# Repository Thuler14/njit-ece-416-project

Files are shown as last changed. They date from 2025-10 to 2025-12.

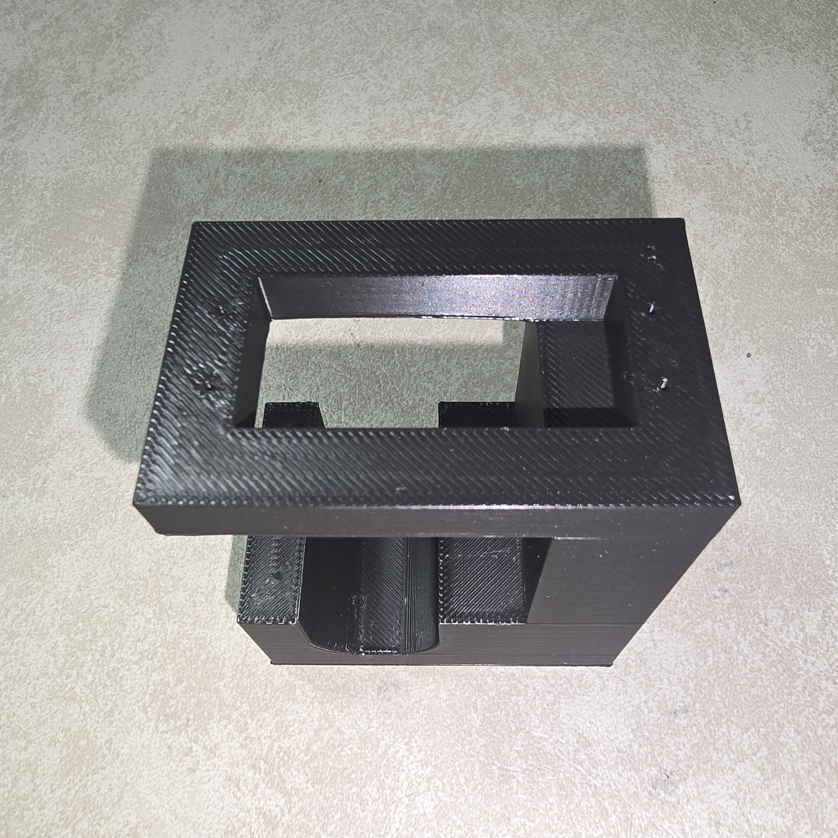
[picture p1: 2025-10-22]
mechanical/photos/m1_servo_mount_3.jpg

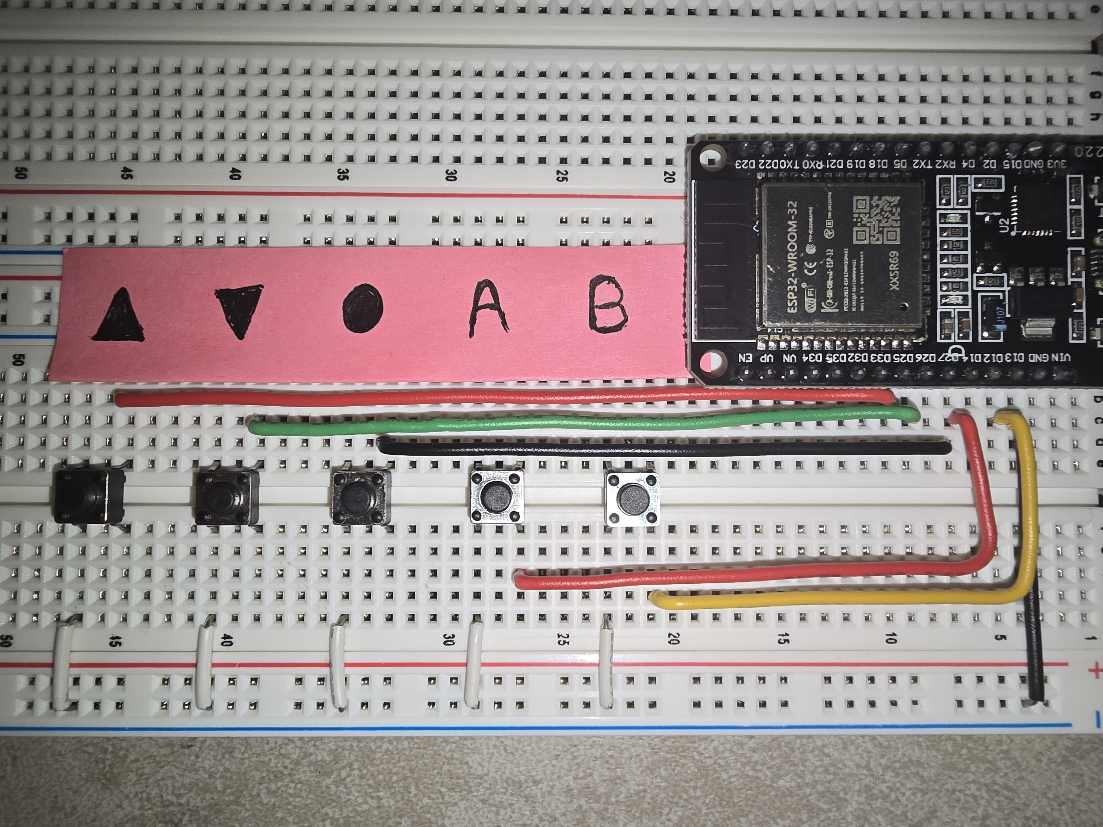
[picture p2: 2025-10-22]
mechanical/photos/m1_push_button_wiring.jpg

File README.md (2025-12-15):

# Automatic Temperature-Controlled Shower

ESP32-based prototype that mixes hot/cold water to a user-selected setpoint using temperature sensors, a servo-driven valve pair, and a simple UI. Built for NJIT ECE 416.

## Quick Start (Arduino IDE)
1. Install **esp32 by Espressif Systems** via Boards Manager.
2. Libraries: **OneWire**, **DallasTemperature**, **ESP32Servo**, **U8g2**.
3. Configure firmware:
   - `firmware/common/config.h`: set control/UI MACs (scan with `firmware/tools/m2_mac_scan/`), comm channel, and optional ESP-NOW encryption keys.
   - `firmware/control/config.h`: set DS18B20 addresses (scan with `firmware/tools/m1_temp_scan/`) and servo min/max values (from `firmware/tools/m1_servo_calibration/`).
4. Build/upload in two IDE windows:
   - `firmware/control/control.ino` → Control unit (sensors, PID, servos, flow, E-stop).
   - `firmware/ui/ui.ino` → UI unit (buttons, OLED, presets, ESP-NOW sender).
5. Power both boards; UI shows outlet temp and link status. Toggle run/stop from the UI. Serial output on the control unit emits CSV logs (10 Hz) when `PID_LOG_CSV` is enabled.

## Data Logging & Plots
- Control firmware prints CSV logs over USB. Capture to file with your serial monitor or use `tests/scripts/m2_logger_live_plot.py --port /dev/tty... --outfile tests/data/run.csv` to live-plot and save.
- Offline plotting: `python3 tests/scripts/m2_logger_plot.py --pattern my_run*.csv` saves PNGs to `tests/reports/`.
- Python deps: `pandas`, `matplotlib`, and `pyserial` (for live logging).

## Repository Structure
```text
njit-ece-416-project/
├─ firmware/
│  ├─ common/           # Shared comm + setpoint config
│  ├─ control/          # ESP32 control unit (sensors, PID, servos)
│  ├─ ui/               # ESP32 UI unit (buttons, OLED, ESP-NOW)
│  ├─ examples/         # Milestone demos
│  ├─ libraries/        # Local Arduino libs (if any)
│  └─ tools/            # Address/servo calibration sketches
├─ mechanical/
│  ├─ cad/              # 3D models, mounts, enclosure
│  └─ photos/           # Assembly & testbed images
├─ tests/
│  ├─ data/             # CSV logs (temp, flow, servo_us, setpoint)
│  ├─ scripts/          # Analysis helpers (optional)
│  └─ reports/          # Validation results & plots
└─ design/              # Wiring diagrams, block diagram, pin maps, calibration notes
```

## Safety
- Max outlet temp **120 °F** (hard limit in firmware).  
- Link-loss or sensor fault → system defaults to **cold-safe**.  
- Hardware E-stop cuts servo power and forces valve closed. 

## Contributing
- Open an Issue first for features/bugfixes; note required hardware (control/UI boards, sensors, flow).
- Work from a fork or branch off `main`. Touch the relevant area (`firmware/`, `tests/`, `mechanical/`, `design/`) and keep evidence in `tests/data` and `tests/reports`.
- Firmware: use the Arduino libs listed above; only change `firmware/common/config.h` and `firmware/control/config.h` when necessary, and document MAC/address updates.
- Scripts/plots: keep deps to `pandas`, `matplotlib`, `pyserial`; include example commands in your PR.
- Open a PR with a concise summary and evidence paths; call out any safety-impacting changes.

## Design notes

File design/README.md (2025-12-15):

# design
System design artifacts: block/wiring diagrams, pin maps, and configuration notes for the ESP32 control + UI units.

## Contents
- `wiring/` — wiring diagrams and pin tables for sensors, servos, flow sensor, E-stop, OLED, and buttons.
- `config/` — design-time notes for ESP-NOW, PID constants, setpoint presets, and component specifics (OLED, temp sensors, flow sensor, buttons, servos).

## Conventions
- Keep editable sources (Draw.io/Fritzing/etc.) next to exported PNG/PDF.
- Note any calibration values or pin swaps that need to be mirrored in `firmware/common/config.h` and `firmware/control/config.h`.

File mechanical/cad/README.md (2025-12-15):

# mechanical/cad
Fusion 360 models for mounts, enclosure pieces, and printable hardware.

## Layout
- `servo_mount/` — bracket to hold the MG996R servo at the valve.
- `valve_coupler/` — coupler between servo horn and valve stem.
- `exports/` — STL exports for printing (name by milestone/task).

Add new variants with a short note on fitment/tolerances; keep param edits in the CAD source and export fresh STLs when dimensions change.

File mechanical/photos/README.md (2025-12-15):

# mechanical/photos
Assembly and testbed photos (wiring, leak tests, waterproofing, mounts).

- Name files by milestone/task (ex: `m2_servo_mount.jpg`, `m3_estop_wiring.jpg`).
- Add a brief caption in a `.md` or `_notes.txt` if the photo shows something non-obvious (orientation, clearances, torque notes).

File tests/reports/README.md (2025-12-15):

# tests/reports
Validation outputs: plots, screenshots, and media from milestone runs (temperature control, safety, leak, flow).

- `tests/scripts/m2_logger_plot.py` writes PNGs here using the CSV stem.
- Name artifacts by milestone/task (ex: `m2_closedloop.png`, `m3_fault_demo.mp4`) and mention the source CSV or hardware setup in the report/PR.

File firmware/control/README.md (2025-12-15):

# firmware/control
ESP32 firmware for the control unit: temperature sensors, PI loop, dual servos, flow sensing, and safety interlocks.

## Setup
- Open `control.ino` in Arduino IDE (ESP32 board support installed).
- Libraries: **OneWire**, **DallasTemperature**, **ESP32Servo**.
- Configure hardware constants in `config.h`:
  - Set DS18B20 ROM addresses (scan with `firmware/tools/m1_temp_scan/`).
  - Servo min/max µs from `firmware/tools/m1_servo_calibration/`.
- Match ESP-NOW MAC/channel/encryption with `firmware/common/config.h`.

## Operation
- Receives setpoint + run/stop from the UI unit via ESP-NOW.
- Polls hot/cold/outlet DS18B20s at 10 Hz with plausibility + rapid-change checks.
- Drives two MG996R servos to mix hot/cold; monitors flow (YF-S201) and E-stop.
- CSV logging (10 Hz) is enabled when `PID_LOG_CSV` is true; capture via USB serial to `tests/data/`. Header: `ms,setF,T_out_raw,T_out_filt,ratio,u,Kp,Ki,flow_lpm,link_ok`.

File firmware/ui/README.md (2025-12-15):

# firmware/ui
ESP32 firmware for the user interface unit: buttons, OLED, presets, and ESP-NOW link to the control unit.

## Setup
- Open `ui.ino` in Arduino IDE (ESP32 board support installed).
- Library: **U8g2** for the SSD1309 OLED.
- Ensure `firmware/common/config.h` MAC/channel/encryption match the control unit.
- Button/OLED pinout lives in `config.h` (defaults: ▲▼● A/B on GPIO 25/26/27/14/13).

## Operation
- Sends setpoint + run/stop to the control unit; sends heartbeat every second.
- UI shortcuts: ▲/▼ adjust setpoint, presets A/B defined in `firmware/common/config.h`.
- Screen shows outlet temp, link status, and flow (when provided by the control unit).
- Control link is over ESP-NOW; update preset values or default setpoint in `firmware/common/config.h`.

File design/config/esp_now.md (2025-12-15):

# ESP-NOW Communication — Configuration

## Overview

- The system uses **ESP-NOW** for direct, low-latency wireless communication between the **Control** and **UI** modules.
- Both ESP32 boards operate in **Station (STA)** mode on a fixed Wi-Fi channel to maintain a stable one-to-one link.
- MAC addresses and encryption keys are configured in [`firmware/config/config.h`](../../firmware/common/config.h).

---

## MAC Addresses

| Constant | Device | Value |
|:--|:--|:--:|
| `COMM_CTRL_MAC` | Control unit | `3C:8A:1F:80:A9:D4` |
| `COMM_UI_MAC` | UI unit | `8C:4F:00:35:9B:F4` |

> Discovered using [`firmware/tools/m2_mac_scan/m2_mac_scan.ino`](../../firmware/tools/m2_mac_scan/m2_mac_scan.ino).

---

## Communication Constants

| Constant | Description | Value |
|:--|:--|:--:|
| `COMM_CHANNEL` | Wi-Fi channel used for both boards | `6` |
| `COMM_USE_ENCRYPTION` | Enable/disable ESP-NOW encryption (`true`/`false`) | `false` |

---

## Encryption Keys

| Constant | Description | Value |
|:--|:--|:--:|
| `COMM_PMK` | Primary Master Key (global) | `showerctrl_pmk16` |
| `COMM_LMK` | Local Master Key (per-peer key) | `static_lmk_uictr` |

---

## Protocol

| Constant | Description | Value |
|:--|:--|:--:|
| `COMM_PROTOCOL_VERSION` | Protocol version | `1` |
| `COMM_FLAG_ACK` | Acknowledgment bit | `1 << 0` |
| `COMM_FLAG_RUN` | Run/Stop bit | `1 << 1` |
| `COMM_FLAG_ERR` | Error bit | `1 << 2` |

---

## Data Structure

`COMM_Payload` defines the transmitted packet containing timestamp, sequence number, setpoint, and flag bits used for control and acknowledgment.

---

## Notes
- Each board uses the **other board’s MAC address** as its peer.
  - UI → `CTRL_MAC`  
  - Control → `UI_MAC`
- Both must share the same **channel** and, if encryption is enabled, the **same PMK/LMK pair**.

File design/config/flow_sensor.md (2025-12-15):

# Flow Sensor (YF-S201) - Configuration

## Overview

- The control module uses one **YF-S201** Hall-effect flow sensor to measure the total outlet flow rate.
- The sensor outputs a digital pulse signal proportional to flow velocity, detected via an interrupt on the ESP32. 
- Configuration constants are defined in [`firmware/control/config.h`](../../firmware/control/config.h).

---

## Hardware Constants

| Constant | Description | Value |
|:--|:--|:--:|
| `FLOW_PIN` | GPIO used for pulse input | `21` |

---

## Measurement Constants

| Constant | Description | Value |
|:--|:--|:--:|
| `FLOW_K_PULSES_PER_ML` | K-factor — pulses per mL of water (≈7500/L) | `7.5f` |
| `FLOW_WINDOW_MS` | Sampling window for pulse counting (ms) | `500` |
| `FLOW_FILTER_TAU_MS` | EMA time constant for smoothing flow readings (ms) | `1000` |

---

## Notes

- The **K-factor (7.5 pulses/mL)** depends on the specific sensor and flow path and will be refined during **M3 calibration**.  
- The current sampling window of **500 ms** balances noise reduction with responsiveness.

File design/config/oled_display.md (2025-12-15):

# OLED Display — Configuration

## Overview

- The system uses a **128×64 px SSD1309** OLED driven over **SPI** using the **U8g2** graphics library.
- It shows setpoint, run state, and status indicators for transmission activity.
- Display configuration is defined in [`firmware/ui/config.h`](../../firmware/ui/config.h).

---

## Hardware Constants

| Constant | Description | Value |
|:--|:--|:--:|
| `OLED_PIN_CS` | Chip Select (CS) | `5` |
| `OLED_PIN_DC` | Data/Command (DC) | `22` |
| `OLED_PIN_RST` | Reset (RST) | `4` |

---

## U8g2 Setup (firmware)

- Rotation: `U8G2_R0` (no rotation)
- Constructor: `U8G2_SSD1309_128X64_NONAME2_F_4W_HW_SPI`

---

## Notes

- Operates on 3.3 V logic.  
- Use full-buffer (`_F_`) U8g2 variants for stable screen refresh.

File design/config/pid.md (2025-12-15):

# PID Controller — Configuration

## Overview

- PI(D) controller drives the hot/cold valve mix ratio to hold the outlet temperature at the setpoint.  
- PID configuration is defined in [`firmware/control/config.h`](../../firmware/control/config.h).

---

## Control Gains and Limits

| Parameter | Description | Value |
|:--|:--|:--:|
| `PID_KP` | Proportional gain | `0.10` |
| `PID_KI` | Integral gain (per second) | `0.08` |
| `PID_KD` | Derivative gain | `0.00` |
| `PID_OUT_MIN` | Output lower bound (mix ratio) | `0.0` |
| `PID_OUT_MAX` | Output upper bound (mix ratio) | `1.0` |

---

## Notes

- Integrator is clamped to `[PID_OUT_MIN, PID_OUT_MAX]` to limit windup.  
- Timing uses measured loop intervals (`millis()` delta) with a 12 ms target delay; retune if the loop rate changes.

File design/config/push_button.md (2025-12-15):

# Push Buttons — Configuration

## Overview

- Five **momentary pushbuttons** provide local user input for temperature control and preset functions.
- Each button is connected to an **ESP32 GPIO** with **internal pull-ups enabled** (active-low).
- Button configuration is defined in [`firmware/ui/config.h`](../../firmware/ui/config.h).

---

## Hardware Constants

| Constant | Description | Value |
|:--|:--|:--:|
| `BTN_PIN_UP` | Increase setpoint (▲) | `25` |
| `BTN_PIN_DOWN` | Decrease setpoint (▼) | `26` |
| `BTN_PIN_OK` | Run/Stop toggle (●) | `27` |
| `BTN_PIN_A` | Preset A | `14` |
| `BTN_PIN_B` | Preset B | `13` |

---

## Timing Constant

| Constant | Description | Value (ms) |
|:--|:--|:--:|
| `BTN_DEBOUNCE_MS` | Time a level must be stable before recognized | `20` |
| `BTN_DBLCLICK_MS` | Maximum time between two clicks | `350` |
| `BTN_LONGPRESS_MS` | Hold duration to count as long-press | `800` |
| `BTN_REPEAT_DELAY_MS` | Wait before first repeat event | `500` |
| `BTN_REPEAT_MS` | Interval between repeats | `150` |

---

## Notes

- Buttons are **active-low**, meaning a press reads `LOW`.
- Presets A and B correspond to user-defined temperature shortcuts.

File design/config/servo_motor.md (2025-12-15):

# Servo Motors (MG-996R) — Configuration

## Overview

- Two **MG996R servo motors** are used to control the cold and hot water valves.  
- Each servo is calibrated for fully closed and fully open positions, with pulse widths defined in [`firmware/control/config.h`](../../firmware/control/config.h).
- The calibration ensures consistent mechanical limits and prevents overtravel.

---

## Hardware Constants

| Constant | Description | Value |
|:--|:--|:--:|
| `SERVO_PIN_HOT` | GPIO pin for hot valve servo | `19` |
| `SERVO_PIN_COLD` | GPIO pin for cold valve servo | `18` |

## Calibration Constants

| Constant | Description | Typical Value (µs) |
|:--|:--|:--:|
| `SERVO_HOT_MIN_US` | Hot valve — fully **open** position | `1180` |
| `SERVO_HOT_MAX_US` | Hot valve — fully **closed** position | `2080` |
| `SERVO_COLD_MIN_US` | Cold valve — fully **open** position | `1120` |
| `SERVO_COLD_MAX_US` | Cold valve — fully **closed** position | `2080` |
| `SERVO_GUARD_US` | Safety margin from mechanical stop | `15` |

> Calibrated using [`firmware/tools/servo_calibration/m1_servo_calibration.ino`](../../firmware/tools/m1_servo_calibration/m1_servo_calibration.ino).

---

## Notes

- Guard offsets prevent mechanical stress by reducing servo travel slightly before reaching the physical stop.
- The calibrated limits correspond to real valve endpoints; any adjustments should be re-measured and updated in `config.h`.

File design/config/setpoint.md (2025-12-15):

# Temperature Setpoint — Configuration

## Overview

- Defines default, safety, and preset temperature values for system operation.  
- Values are expressed in **degrees Fahrenheit (°F)**.  
- Configuration is defined in [`firmware/ui/config.h`](../../firmware/common/config.h).

---

## Setpoint Constants

| Constant | Description | Value (°F) |
|:--|:--|:--:|
| `SETPOINT_DEFAULT_F` | Default setpoint at startup | `100.0` |
| `SETPOINT_MIN_F` | Minimum safety limit | `80.0` |
| `SETPOINT_MAX_F` | Maximum safety limit | `120.0` |
| `SETPOINT_STEP_F` | Adjustment step size | `1.0` |
| `SETPOINT_PRESET_A_F` | Preset A value | `98.0` |
| `SETPOINT_PRESET_B_F` | Preset B value | `105.0` |

---

## Notes

- All limits are enforced in firmware to prevent unsafe temperature selection.  
- Preset A and B provide quick access to preferred comfort temperatures.

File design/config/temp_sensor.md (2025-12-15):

# Temperature Sensors (DS18B20) - Configuration

## Overview

- The control module uses three DS18B20 digital temperature sensors connected via a shared OneWire bus.  
- Each sensor has a unique 64-bit ROM address and is configured in [`firmware/control/config.h`](../../firmware/control/config.h).

---

## Hardware Constants 

| Constant | Description | Value |
|:--|:--|:--:|
| `TEMP_PIN_ONEWIRE` | GPIO pin for DS18B20 data line | `4` |
| `TEMP_HOT_ADDR` | Hot inlet sensor | `0x289DE1BA00000078` |
| `TEMP_COLD_ADDR` | Cold inlet sensor | `0x2884B3B4000000B6` |
| `TEMP_OUT_ADDR` | Outlet sensor | `0x284DF1BA000000C0` |

> Discovered using [`firmware/tools/m1_temp_scan/m1_temp_scan.ino`](../../firmware/tools/m1_temp_scan/m1_temp_scan.ino).

---

## Timing Constants

| Constant | Description | Value |
|:--|:--|:--:|
| `TEMP_RESOLUTION` | DS18B20 resolution (9–12 bits) | `9` |
| `TEMP_CONVERSION_TIME_MS` | Max conversion time for chosen resolution | `94` |
| `TEMP_LOOP_DT_MS` | Loop interval for temperature read (ms) | `100` |

---

## Filtering Constants

| Constant | Description | Value |
|:--|:--|:--:|
| `TEMP_EMA_ALPHA` | EMA smoothing factor (τ ≈ 0.4 s @ 10 Hz) | `0.20f` |
| `TEMP_MIN_VALID_C` | Minimum valid temperature (°C) | `-60.0f` |
| `TEMP_MAX_VALID_C` | Maximum valid temperature (°C) | `125.0f` |

---

## Notes

- ROM addresses are unique identifiers used to bind each DS18B20 to its physical position.  
- Configuration constants apply globally to all temperature sensors unless overridden.  
- 9-bit mode allows a full conversion within the 100 ms loop.

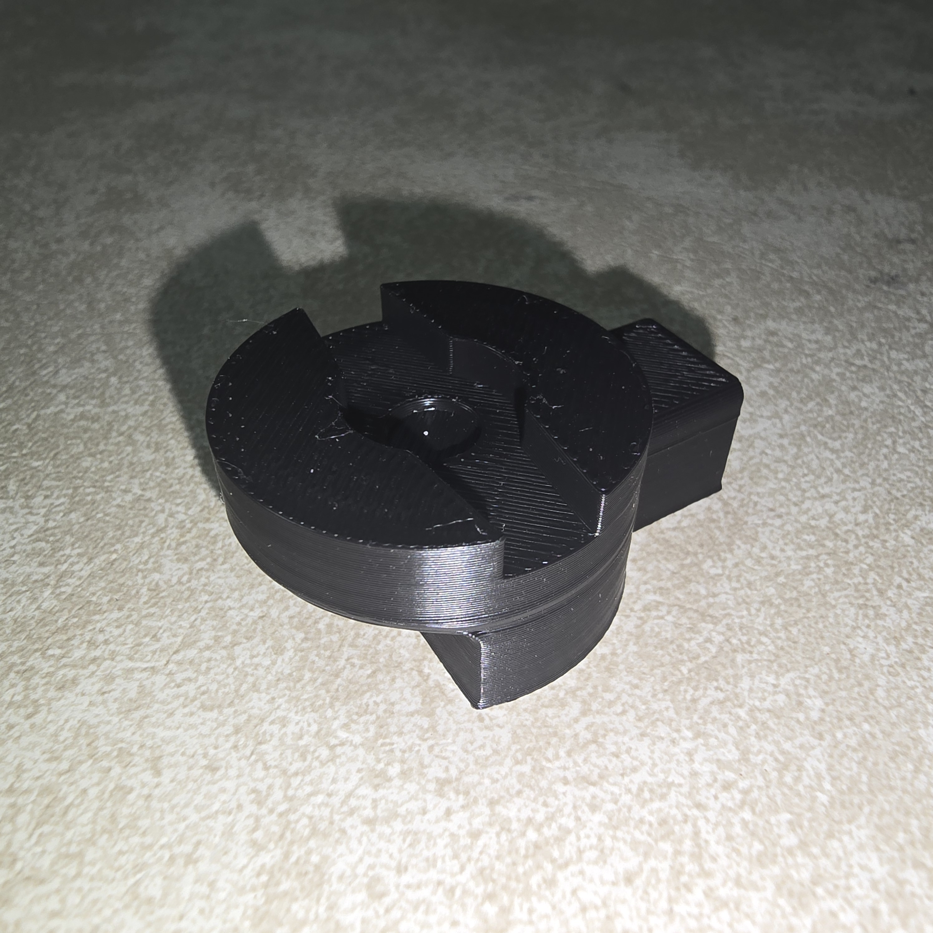
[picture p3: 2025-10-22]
mechanical/photos/m1_valve_coupler_1.jpg

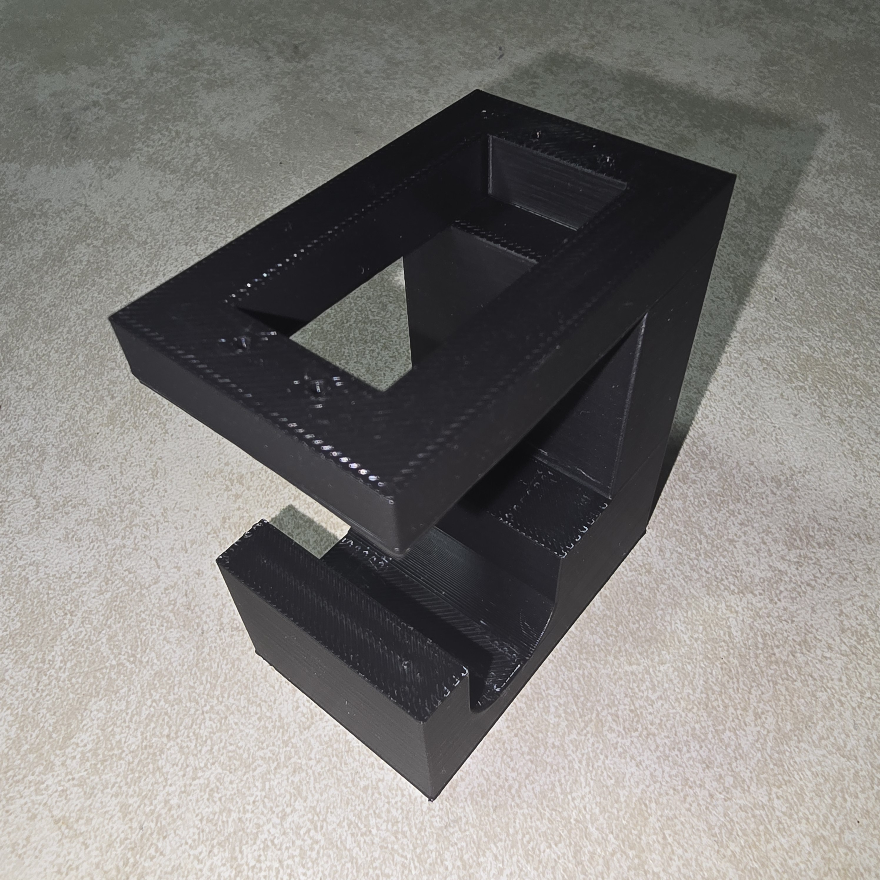
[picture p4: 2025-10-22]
mechanical/photos/m1_servo_mount_1.jpg

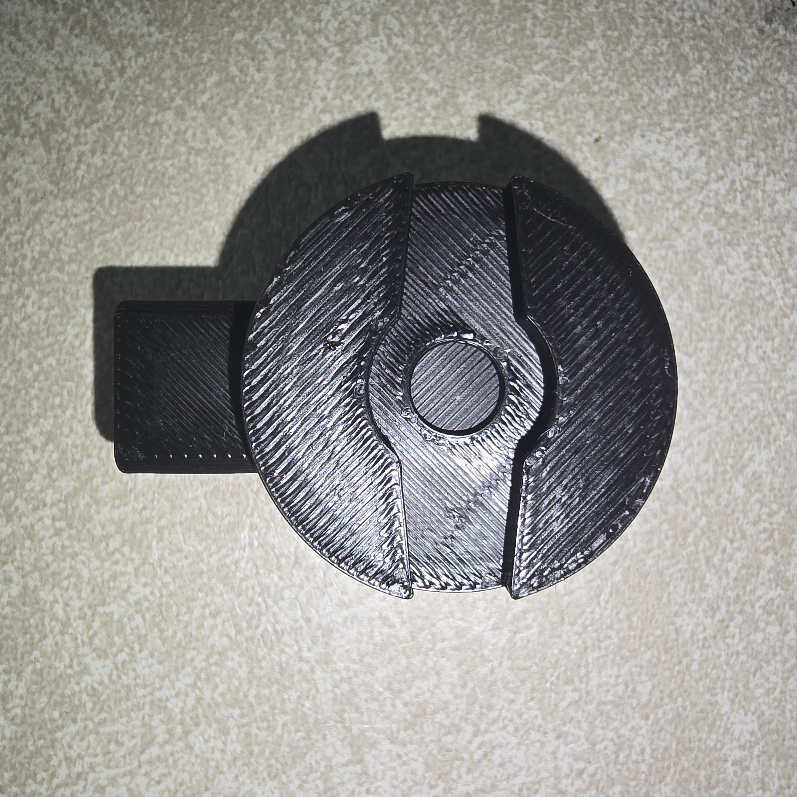
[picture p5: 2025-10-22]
mechanical/photos/m1_valve_coupler_2.jpg

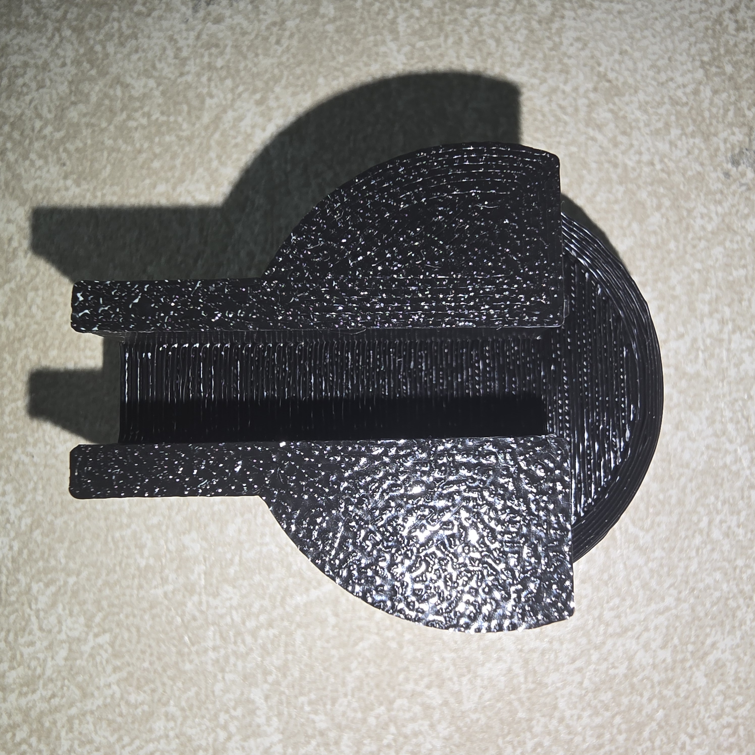
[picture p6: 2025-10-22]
mechanical/photos/m1_valve_coupler_3.jpg

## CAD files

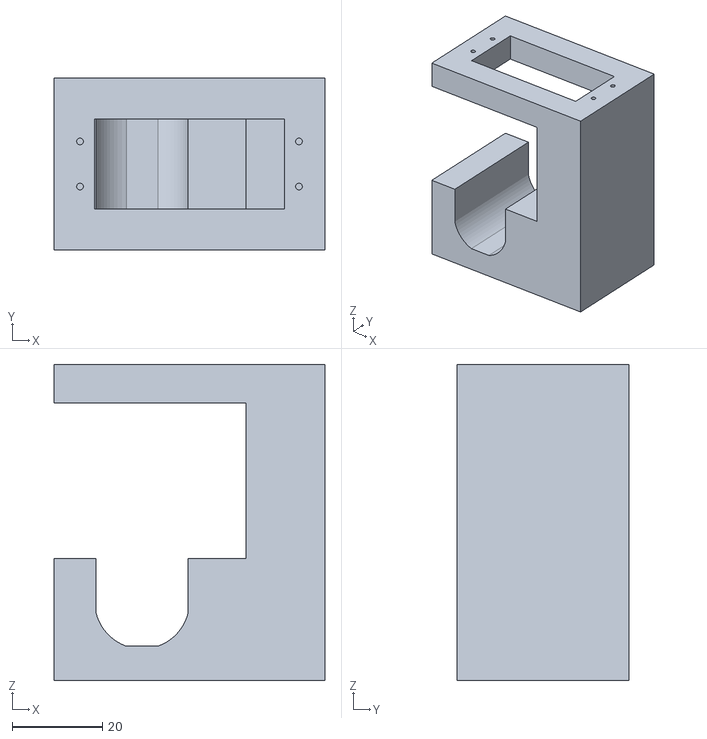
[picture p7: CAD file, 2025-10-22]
mechanical/cad/exports/valve_coupler.stl
60.0 x 38.0 x 70.0

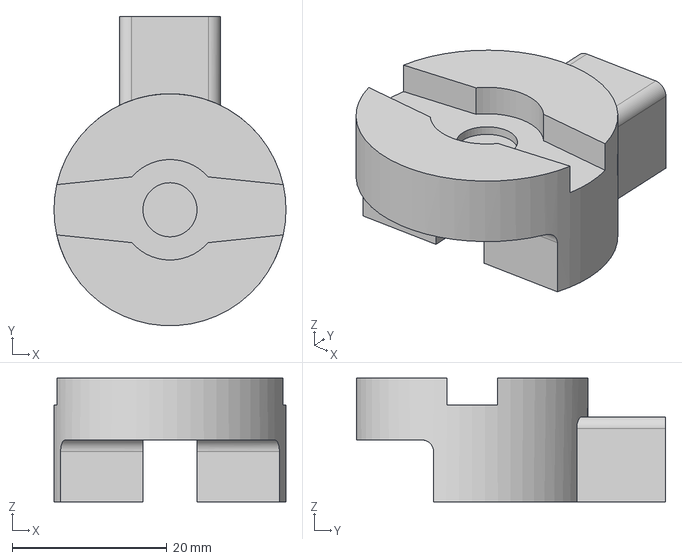
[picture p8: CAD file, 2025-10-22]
mechanical/cad/valve_coupler/valve_coupler.step
30.0 x 40.0 x 16.0 mm

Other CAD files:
mechanical/cad/servo_mount/servo_mount.step
mechanical/cad/exports/servo_mount.stl
mechanical/cad/servo_mount/servo_mount.f3d
mechanical/cad/valve_coupler/valve_coupler.f3d

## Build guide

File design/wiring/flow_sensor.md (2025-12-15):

# Flow Sensor (YF-S201) — Wiring

One **YF-S201** Hall-effect flow sensor is used to measure the total outlet water flow rate.

**Pull-up:** One 10 kΩ resistor between **GPIO 21** and **3V3**

| Wire Color | Signal | ESP32 Pin |
|:--|:--|:--:|
| Yellow | Flow Signal | GPIO 21 |
| Red | VCC | 5V |
| Black | GND | GND |

> 📷 Photo: [`mechanical/photos/m2_flow_sensor_wiring.jpg`](../../mechanical/photos/m2_flow_sensor_wiring.jpg)

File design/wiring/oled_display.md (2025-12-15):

# OLED Display (SSD1309 SPI Blue) — Wiring

The **128×64 px SSD1309** OLED connects via a ESP32’s **VSPI bus** using a **4-wire SPI interface** compatible with **U8g2**.

- **Bus type:** VSPI (SPI 4-wire + CS)

| OLED Pin | Signal | ESP32 Pin |
|:--|:--|:--:|
| 1 | GND | GND |
| 2 | VCC | 3V3 |
| 3 | SCK | GPIO 18 |
| 4 | SDA / MOSI | GPIO 23 |
| 5 | RES / RST | GPIO 4 |
| 6 | DC | GPIO 22 |
| 7 | CS | GPIO 5 |

> 📷 Photo: [`mechanical/photos/m1_oled_display_wiring.jpg`](../../mechanical/photos/m1_oled_display_wiring.jpg)

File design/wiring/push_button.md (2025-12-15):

# Push Button - Wiring

Five momentary push buttons are used for the UI (active-low with internal pull-ups).

| Button | Function | ESP32 Pin |
|:--:|:--|:--:|
| ▲ | Up | GPIO 25 |
| ▼ | Down | GPIO 26 |
| ● | Center / OK | GPIO 27 |
| A | Action A | GPIO 14 |
| B | Action B | GPIO 13 |

> 📷 Photo: [`mechanical/photos/m1_push_button_wiring.jpg`](../../mechanical/photos/m1_push_button_wiring.jpg)

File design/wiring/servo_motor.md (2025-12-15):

# Servo Motors (Cold / Hot Valves) — Wiring

Two MG996R servos are used to control the cold and hot water valves.

**Power:** 6 V DC supply (≥ 3 A) shared by both servos.  
**Common ground:** Connect 6 V GND to ESP32 GND.

| Servo | Signal | ESP32 Pin |
|:--|:--|:--:|
| Cold Valve | PWM | GPIO 18 |
| Hot Valve | PWM | GPIO 19 |
| Both | V+ | 6 V |
| Both | GND | GND |

> 📷 Photo: [`mechanical/photos/m1_servo_motor_wiring.jpg`](../../mechanical/photos/m1_servo_motor_wiring.jpg)

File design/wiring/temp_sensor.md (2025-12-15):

# Temperature Sensors (DS18B20) — Wiring

Three DS18B20 temperature sensors are used to measure the hot, cold, and mixed water temperatures.

**Pull-up:** One 4.7 kΩ resistor between **GPIO 4** and **3V3**

| Wire Color | Signal | ESP32 Pin |
|:--|:--|:--:|
| Yellow | DQ | GPIO 4 |
| Red | VDD | 3V3 |
| Blue | GND | GND |

> 📷 Photo: [`mechanical/photos/m1_temp_sensor_wiring.jpg`](../../mechanical/photos/m1_temp_sensor_wiring.jpg)

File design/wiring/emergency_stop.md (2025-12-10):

# Emergency Stop Button - Wiring

Single momentary push button used to cut servo drive in firmware (active-low with internal pull-up).

| Signal | ESP32 Pin | Notes |
|:--|:--:|:--|
| E-STOP | GPIO 33 | Input with `INPUT_PULLUP`; momentary push to GND triggers E-stop |

Recommendation: wire the button to short the pin to GND when pressed. Keep leads short and routed away from servo power to reduce noise pickup.

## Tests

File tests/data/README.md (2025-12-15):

# tests/data
Raw test captures (CSV). Standard control logger header (10 Hz):

```
ms,setF,T_out_raw,T_out_filt,ratio,u,Kp,Ki,flow_lpm,link_ok
```

Keep files named by milestone/task (ex: `m2_closedloop_*.csv`, `setpoint_auto_*.csv`). Live serial captures from `m2_logger_live_plot.py` can be saved directly here for later plotting. If you add extra columns (e.g., additional sensors), document them in the test report.

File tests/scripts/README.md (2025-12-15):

# tests/scripts
Python helpers to plot control logs and milestone test data.

## Setup
- `python3 -m pip install pandas matplotlib pyserial` (pyserial only needed for live logging).
- Run scripts from the repo root so relative paths to `tests/data/` and `tests/reports/` resolve.

## Scripts
- `m2_logger_live_plot.py` — stream the control unit CSV logger over serial, live-plot, and optionally save (`--port /dev/tty... --outfile tests/data/run.csv`).
- `m2_logger_plot.py` — batch-plot CSVs in `tests/data/` and save PNGs to `tests/reports/` (patterns via `--pattern`).
- `m2_flow_sensor_test_plot.py` — dual-axis plot for YF-S201 calibration captures.
- `m2_outlet_temp_test_plot.py` — raw vs filtered outlet temperature from the 10 Hz read loop.
- `m2_closed_loop_v1_plot.py` — PID step response plot (outlet vs setpoint).

Use `python3 tests/scripts/<script>.py --help` for arguments and expected input files.

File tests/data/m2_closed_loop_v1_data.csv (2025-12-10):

t_ms | out_f | set_f | error_f | ratio
0 | 85.97 | 84.0 | -1.97 | 0.2
12 | 85.97 | 84.0 | -1.97 | 0.2
24 | 85.97 | 84.0 | -1.97 | 0.2
36 | 85.79 | 84.0 | -1.79 | 0.21
48 | 85.79 | 84.0 | -1.79 | 0.21
60 | 85.79 | 84.0 | -1.79 | 0.21
72 | 85.66 | 84.0 | -1.66 | 0.22
84 | 85.66 | 84.0 | -1.66 | 0.22
96 | 85.66 | 84.0 | -1.66 | 0.22
108 | 85.54 | 84.0 | -1.54 | 0.23
120 | 85.54 | 84.0 | -1.54 | 0.23
132 | 85.54 | 84.0 | -1.54 | 0.22
144 | 85.46 | 84.0 | -1.46 | 0.23
156 | 85.46 | 84.0 | -1.46 | 0.23
168 | 85.46 | 84.0 | -1.46 | 0.23
180 | 85.38 | 84.0 | -1.38 | 0.23
192 | 85.38 | 84.0 | -1.38 | 0.23
204 | 85.38 | 84.0 | -1.38 | 0.23
216 | 85.33 | 84.0 | -1.33 | 0.24
228 | 85.33 | 84.0 | -1.33 | 0.23
240 | 85.33 | 84.0 | -1.33 | 0.23
252 | 85.28 | 84.0 | -1.28 | 0.24
264 | 85.28 | 84.0 | -1.28 | 0.24
276 | 85.28 | 84.0 | -1.28 | 0.23
288 | 85.25 | 84.0 | -1.25 | 0.24
300 | 85.25 | 84.0 | -1.25 | 0.24
312 | 85.25 | 84.0 | -1.25 | 0.23
324 | 85.22 | 84.0 | -1.22 | 0.24
336 | 85.22 | 84.0 | -1.22 | 0.23
348 | 85.22 | 84.0 | -1.22 | 0.23
360 | 85.01 | 84.0 | -1.01 | 0.25
372 | 85.01 | 84.0 | -1.01 | 0.25
384 | 85.01 | 84.0 | -1.01 | 0.25
396 | 84.85 | 84.0 | -0.85 | 0.27
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

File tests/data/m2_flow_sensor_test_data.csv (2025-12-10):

t_ms | Hz | L_per_min
500 | 38.000 | 0.3040
1000 | 36.000 | 0.2880
1500 | 38.000 | 0.3040
2000 | 36.000 | 0.2880
2500 | 38.000 | 0.3040
3000 | 36.000 | 0.2880
3500 | 38.000 | 0.3040
4000 | 36.000 | 0.2880
4500 | 38.000 | 0.3040
5000 | 36.000 | 0.2880
5500 | 36.000 | 0.2880
6000 | 36.000 | 0.2880
6500 | 36.000 | 0.2880
7000 | 36.000 | 0.2880
7500 | 36.000 | 0.2880
8000 | 38.000 | 0.3040
8500 | 36.000 | 0.2880
9000 | 36.000 | 0.2880
9500 | 38.000 | 0.3040
10000 | 36.000 | 0.2880
10500 | 36.000 | 0.2880
11000 | 36.000 | 0.2880
11500 | 38.000 | 0.3040
12000 | 36.000 | 0.2880
12500 | 36.000 | 0.2880
13000 | 38.000 | 0.3040
13500 | 36.000 | 0.2880
14000 | 36.000 | 0.2880
14500 | 36.000 | 0.2880
15000 | 34.000 | 0.2720
15500 | 38.000 | 0.3040
16000 | 36.000 | 0.2880
16500 | 34.000 | 0.2720
17000 | 34.000 | 0.2720
17500 | 36.000 | 0.2880
18000 | 30.000 | 0.2400
18500 | 36.000 | 0.2880
19000 | 32.000 | 0.2560
19500 | 30.000 | 0.2400
20000 | 36.000 | 0.2880
20500 | 36.000 | 0.2880
21000 | 34.000 | 0.2720
21500 | 34.000 | 0.2720
22000 | 36.000 | 0.2880
22500 | 34.000 | 0.2720
23000 | 36.000 | 0.2880
23500 | 34.000 | 0.2720
24000 | 34.000 | 0.2720
24500 | 36.000 | 0.2880
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

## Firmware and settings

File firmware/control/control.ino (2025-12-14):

/*
 * ================================================================
 *  Module: control
 *  Purpose: Handles the control logic for the shower controller.
 *           Receives setpoint and run-state commands from the UI Unit,
 *           reads temperature sensors, and drives the servo valves
 *           to maintain the desired outlet temperature.
 *
 *  Hardware:
 *    - ESP32 Control Unit (WIFI_STA)
 *    - 3× DS18B20 sensors (Hot, Cold, Outlet)
 *    - 2× MG996R servos (Hot, Cold)
 *    - 1x YF-S201 flow sensor (Outlet)
 *
 *  Communication:
 *    - Receives setpoint and run-state data from UI Unit via ESP-NOW
 *    - Sends ACK/ERR responses
 *    - Optional encryption using PMK/LMK
 * ================================================================
 */

#include <math.h>
#include <stdio.h>

#include "../common/config.h"
#include "communication.h"
#include "config.h"
#include "flow_sensor.h"
#include "pid.h"
#include "temperature.h"
#include "valve_mix.h"

static constexpr uint16_t LOOP_DELAY_MS = 12;
static constexpr uint16_t LOGGER_PERIOD_MS = 100;
static PID pi(PID_KP, PID_KI, PID_KD, PID_OUT_MIN, PID_OUT_MAX);

static float setpointF = SETPOINT_DEFAULT_F;
static bool runFlag = false;
static uint32_t lastOutletSampleMs = 0;
static bool loggerHeaderPrinted = false;
static float lastRatio = 0.0f;
static float lastU = 0.0f;
static float lastHotRapidF = 0.0f;
static float lastColdRapidF = 0.0f;
static uint32_t lastHotRapidMs = 0;
static uint32_t lastColdRapidMs = 0;
static void logCsvIfDue(unsigned long nowMs, const TemperatureReading& outlet, bool linkOk);
static bool estopPressed();

enum class FaultCode : uint8_t {
  None = 0,
  EStop,
  LinkLoss,
  OutletSensorFault,
  OutletOutOfBounds,
  HotSensorFault,
  ColdSensorFault,
  HotOutOfBounds,
  ColdOutOfBounds,
  HotRapidChange,
  ColdRapidChange,
};

static FaultCode activeFault = FaultCode::None;

static void enterSafeState(const char* reason) {
  if (reason != nullptr) {
    Serial.println(reason);
  }
  valveMixCloseAll();
  pi.reset();
  lastOutletSampleMs = 0;
}

void setup() {
  Serial.begin(115200);
  delay(100);

  if (!commInit())
    while (1) delay(1000);

  pinMode(ESTOP_PIN, INPUT_PULLUP);

  if (!flowSensorInit()) {
    Serial.println("FLOW WARN: Flow sensor init failed");
  }

  if (!temperatureInit()) {
    Serial.println("TEMP ERROR: No DS18B20 sensors detected");
  }

  valveMixInit();
  valveMixCloseAll();
}

void loop() {
  (void) temperatureService();
  (void) flowSensorUpdate();

  const unsigned long nowMs = millis();
  const unsigned long lastRxMs = commLastRxMs();
  const bool linkOk =
      (lastRxMs != 0) && ((unsigned long) (nowMs - lastRxMs) <= COMM_LINK_TIMEOUT_MS);
  const FlowReading flow = flowSensorGet();

  CommCommand cmd{};
  if (commPollCommand(cmd)) {
    if (cmd.lastOk) {
      setpointF = constrain(cmd.setpointF, SETPOINT_MIN_F, SETPOINT_MAX_F);
      runFlag = cmd.runFlag;
      if (!PID_LOG_CSV) {
        Serial.printf("CTRL<-UI setpoint=%.1fF run=%s seq=%lu\n",
                      setpointF,
                      runFlag ? "ON" : "OFF",
                      (unsigned long) cmd.lastSeq);
      }
    } else {
      if (!PID_LOG_CSV) {
        Serial.printf("CTRL<-UI RX failed\n");
      }
    }
  }

  FaultCode detectedFault = FaultCode::None;
  const char* faultMsg = nullptr;
  char boundsMsg[96];
  char hotBoundsMsg[96];
  char coldBoundsMsg[96];
  char rapidMsg[96];

  const bool estop = estopPressed();
  const TemperatureReading& outlet = temperatureGetReading(TempSensor::OUTLET);
  const TemperatureReading& hot = temperatureGetReading(TempSensor::HOT);
  const TemperatureReading& cold = temperatureGetReading(TempSensor::COLD);
  commUpdateOutletTemp(outlet.filteredF, outlet.present && outlet.valid, flow.lpm, flow.sampleMs != 0);
  if (estop) {
    detectedFault = FaultCode::EStop;
    faultMsg = "E-STOP: switch active → closing valves";
    runFlag = false;
  } else {
    if (runFlag &&
        (lastRxMs == 0 || (unsigned long) (nowMs - lastRxMs) > COMM_LINK_TIMEOUT_MS)) {
      detectedFault = FaultCode::LinkLoss;
      faultMsg = "LINK ERROR: No UI command for 2s → closing valves";
      runFlag = false;
      commMarkLinkLost();
    }

    if (detectedFault == FaultCode::None && runFlag) {
      if (!hot.present || !hot.valid) {
        detectedFault = FaultCode::HotSensorFault;
        faultMsg = "TEMP ERROR: Hot sensor fault → closing valves";
        runFlag = false;
      } else if (!cold.present || !cold.valid) {
        detectedFault = FaultCode::ColdSensorFault;
        faultMsg = "TEMP ERROR: Cold sensor fault → closing valves";
        runFlag = false;
      } else if (hot.filteredF < HOT_MIN_PLAUSIBLE_F || hot.filteredF > HOT_MAX_PLAUSIBLE_F) {
        detectedFault = FaultCode::HotOutOfBounds;
        snprintf(hotBoundsMsg,
                 sizeof(hotBoundsMsg),
                 "TEMP ERROR: Hot %.1fF out of bounds (%.0f-%.0fF) → closing valves",
                 hot.filteredF,
                 HOT_MIN_PLAUSIBLE_F,
                 HOT_MAX_PLAUSIBLE_F);
        faultMsg = hotBoundsMsg;
        runFlag = false;
      } else if (cold.filteredF < COLD_MIN_PLAUSIBLE_F || cold.filteredF > COLD_MAX_PLAUSIBLE_F) {
        detectedFault = FaultCode::ColdOutOfBounds;
        snprintf(coldBoundsMsg,
                 sizeof(coldBoundsMsg),
                 "TEMP ERROR: Cold %.1fF out of bounds (%.0f-%.0fF) → closing valves",
                 cold.filteredF,
                 COLD_MIN_PLAUSIBLE_F,
                 COLD_MAX_PLAUSIBLE_F);
        faultMsg = coldBoundsMsg;
        runFlag = false;
      } else {
        // Rapid change detection for hot/cold lines
        if (hot.sampleMs != 0 && lastHotRapidMs != 0) {
          const uint32_t dtMs = hot.sampleMs - lastHotRapidMs;
          if (dtMs > 0 && dtMs <= TEMP_RAPID_WINDOW_MS &&
              fabs(hot.filteredF - lastHotRapidF) >= TEMP_RAPID_DELTA_F) {
            detectedFault = FaultCode::HotRapidChange;
            snprintf(rapidMsg,
                     sizeof(rapidMsg),
                     "TEMP ERROR: Hot jump %.1fF in %lums → closing valves",
                     fabs(hot.filteredF - lastHotRapidF),
                     (unsigned long) dtMs);
            faultMsg = rapidMsg;
            runFlag = false;
          }
        }

        if (detectedFault == FaultCode::None && cold.sampleMs != 0 && lastColdRapidMs != 0) {
          const uint32_t dtMs = cold.sampleMs - lastColdRapidMs;
          if (dtMs > 0 && dtMs <= TEMP_RAPID_WINDOW_MS &&
              fabs(cold.filteredF - lastColdRapidF) >= TEMP_RAPID_DELTA_F) {
            detectedFault = FaultCode::ColdRapidChange;
            snprintf(rapidMsg,
                     sizeof(rapidMsg),
                     "TEMP ERROR: Cold jump %.1fF in %lums → closing valves",
                     fabs(cold.filteredF - lastColdRapidF),
                     (unsigned long) dtMs);
            faultMsg = rapidMsg;
            runFlag = false;
          }
        }

        if (detectedFault == FaultCode::None) {
          if (!outlet.present || !outlet.valid) {
            detectedFault = FaultCode::OutletSensorFault;
            faultMsg = "TEMP ERROR: Outlet sensor fault → closing valves";
            runFlag = false;
          } else if ((outlet.filteredF < OUTLET_MIN_PLAUSIBLE_F) ||
                     (outlet.filteredF > OUTLET_MAX_PLAUSIBLE_F)) {
            detectedFault = FaultCode::OutletOutOfBounds;
            snprintf(boundsMsg,
                     sizeof(boundsMsg),
                     "TEMP ERROR: Outlet %.1fF out of bounds (%.0f-%.0fF) → closing valves",
                     outlet.filteredF,
                     OUTLET_MIN_PLAUSIBLE_F,
                     OUTLET_MAX_PLAUSIBLE_F);
            faultMsg = boundsMsg;
            runFlag = false;
          }
        }
      }
    }
  }

  if (detectedFault != FaultCode::None) {
    if (activeFault != detectedFault || detectedFault == FaultCode::OutletOutOfBounds) {
      enterSafeState(faultMsg);
    } else {
      enterSafeState(nullptr);
    }
    activeFault = detectedFault;
    logCsvIfDue(nowMs, outlet, linkOk);
    delay(LOOP_DELAY_MS);
    return;
  }

  if (!runFlag) {
    activeFault = FaultCode::None;
    enterSafeState(nullptr);
    logCsvIfDue(nowMs, outlet, linkOk);
    if (!PID_LOG_CSV) {
      Serial.printf("RUN=OFF | OUT=%.2fF | SET=%.2fF | link=%s | flow=%.2f L/min\n",
                    outlet.filteredF,
                    setpointF,
                    linkOk ? "OK" : "LOST",
                    flow.lpm);
    }
    delay(LOOP_DELAY_MS);
    return;
  }

  activeFault = FaultCode::None;
  if (hot.sampleMs != 0) {
    lastHotRapidF = hot.filteredF;
    lastHotRapidMs = hot.sampleMs;
  }
  if (cold.sampleMs != 0) {
    lastColdRapidF = cold.filteredF;
    lastColdRapidMs = cold.sampleMs;
  }
  const float outletTempF = outlet.filteredF;
  const uint32_t sampleMs = outlet.sampleMs;
  if (sampleMs == 0 || sampleMs == lastOutletSampleMs) {
    logCsvIfDue(nowMs, outlet, linkOk);
    delay(LOOP_DELAY_MS);
    return;
  }

  // Initial mixing logic using cold and hot sensors
  static bool initialMixingDone = false;

  // Only do initial mixing if not done and outlet is far from setpoint
  if (!initialMixingDone && hot.present && cold.present && hot.valid && cold.valid) {
    // Extra smoothing filter for initial mixing
    static float hotFiltered = 0.0f;
    static float coldFiltered = 0.0f;
    constexpr float alpha = 0.2f; // Smoothing factor (0.0-1.0)
    if (hotFiltered == 0.0f) hotFiltered = hot.filteredF;
    if (coldFiltered == 0.0f) coldFiltered = cold.filteredF;
    hotFiltered = alpha * hot.filteredF + (1.0f - alpha) * hotFiltered;
    coldFiltered = alpha * cold.filteredF + (1.0f - alpha) * coldFiltered;
    // Calculate mix ratio to get as close as possible to setpoint
    float hotF = hotFiltered;
    float coldF = coldFiltered;
    // Avoid division by zero
    if (fabs(hotF - coldF) > 0.1f) {
      float initialRatio = (setpointF - coldF) / (hotF - coldF);
      initialRatio = constrain(initialRatio, 0.0f, 1.0f);
      applyMixRatio(initialRatio);
      lastRatio = initialRatio;
      if (!PID_LOG_CSV) {
        Serial.printf("Initial mixing (filtered): HOT=%.2fF, COLD=%.2fF, SET=%.2fF, ratio=%.2f\n", hotF, coldF, setpointF, initialRatio);
      }
      // If outlet is within 1°F of setpoint, switch to PID
      if (fabs(outletTempF - setpointF) < 1.0f) {
        initialMixingDone = true;
        pi.reset(); // Reset PID for clean start
      }
      logCsvIfDue(sampleMs, outlet, linkOk);
      delay(LOOP_DELAY_MS);
      return;
    }
  }

  // PID control after initial mixing
  initialMixingDone = true; // fallback if sensors not present/valid
  const float dtSec = (lastOutletSampleMs == 0)
                          ? (TEMP_LOOP_DT_MS / 1000.0f)
                          : (sampleMs - lastOutletSampleMs) / 1000.0f;
  lastOutletSampleMs = sampleMs;

  float errorF = setpointF - outletTempF;
  if (fabs(errorF) < PID_ERROR_DEADBAND_F) {
    errorF = 0.0f; // Hold near setpoint to avoid hunting
  }

  const float rawRatio = pi.update(errorF, dtSec);

  // Slew-limit ratio to avoid abrupt swings; allow faster moves when far from setpoint
  const float slewPerSec = (fabs(errorF) > PID_SLEW_ERROR_THRESH_F)
                               ? PID_OUTPUT_SLEW_FAST_PER_SEC
                               : PID_OUTPUT_SLEW_PER_SEC;
  const float maxStep = slewPerSec * dtSec;
  float ratioStep = rawRatio - lastRatio;
  ratioStep = constrain(ratioStep, -maxStep, maxStep);
  const float ratio = constrain(lastRatio + ratioStep, PID_OUT_MIN, PID_OUT_MAX);
  lastU = pi.lastOutput();
  lastRatio = ratio;
  applyMixRatio(ratio);

  if (PID_LOG_CSV) {
    logCsvIfDue(sampleMs, outlet, linkOk);
  } else {
    Serial.printf("RUN=ON | OUT=%.2fF / SET=%.2fF | error=%.2fF | ratio=%.2f | flow=%.2f L/min | link=%s\n",
                  outletTempF,
                  setpointF,
                  errorF,
                  ratio,
                  flow.lpm,
                  linkOk ? "OK" : "LOST");
  }

  delay(LOOP_DELAY_MS);
}

static bool estopPressed() {
  return digitalRead(ESTOP_PIN) == LOW;
}

static void logCsvIfDue(unsigned long nowMs, const TemperatureReading& outlet, bool linkOk) {
  if (!PID_LOG_CSV) return;

  static unsigned long lastLogMs = 0;
  if (lastLogMs != 0 && (nowMs - lastLogMs) < LOGGER_PERIOD_MS) {
    return;
  }

  if (!loggerHeaderPrinted) {
    Serial.println("ms,setF,T_out_raw,T_out_filt,ratio,u,Kp,Ki,flow_lpm,link_ok");
    loggerHeaderPrinted = true;
  }

  const FlowReading flow = flowSensorGet();

  Serial.printf("%lu,%.1f,%.2f,%.2f,%.3f,%.3f,%.3f,%.3f,%.3f,%d\n",
                (unsigned long) nowMs,
                setpointF,
                outlet.rawF,
                outlet.filteredF,
                lastRatio,
                lastU,
                pi.getKp(),
                pi.getKi(),
                flow.lpm,
                linkOk ? 1 : 0);

  lastLogMs = nowMs;
}

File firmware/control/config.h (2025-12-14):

#pragma once

#include <stdint.h>

using DeviceAddress = uint8_t[8];

// ====================================================
// Temperature Sensors (DS18B20)
// ====================================================

constexpr uint8_t TEMP_PIN_ONEWIRE = 4;           // DS18B20 data line (GPIO 4)
constexpr uint8_t TEMP_RESOLUTION = 9;            // 9-bit (~93.75 ms conversion, 0.5°C step)
constexpr unsigned TEMP_CONVERSION_TIME_MS = 94;  // Max conversion time at 9-bit resolution
constexpr unsigned TEMP_LOOP_DT_MS = 100;         // 10 Hz polling rate
constexpr float TEMP_MIN_VALID_C = -60.0f;        // Minimum valid temperature (°C)
constexpr float TEMP_MAX_VALID_C = 125.0f;        // Maximum valid temperature (°C)
constexpr float TEMP_EMA_ALPHA = 0.20f;           // EMA filter (τ ≈ 0.4 s @10 Hz)

// Plausibility window for outlet control logic (°F)
constexpr float OUTLET_MIN_PLAUSIBLE_F = 32.0f;
constexpr float OUTLET_MAX_PLAUSIBLE_F = 140.0f;

// Plausibility for individual lines (°F)
constexpr float HOT_MIN_PLAUSIBLE_F = 50.0f;
constexpr float HOT_MAX_PLAUSIBLE_F = 140.0f;
constexpr float COLD_MIN_PLAUSIBLE_F = 32.0f;
constexpr float COLD_MAX_PLAUSIBLE_F = 90.0f;

// Rapid change detection
constexpr float TEMP_RAPID_DELTA_F = 12.0f;          // Trigger if jump exceeds this delta
constexpr unsigned TEMP_RAPID_WINDOW_MS = 1000;      // Time window for rapid change check

// --- Sensor ROM Addresses ---
// Scanned using: firmware/tools/m1_temp_scan/m1_temp_scan.ino
const DeviceAddress TEMP_HOT_ADDR = {0x28, 0x9D, 0xE1, 0xBA, 0x00, 0x00, 0x00, 0x78};   // Hot line
const DeviceAddress TEMP_COLD_ADDR = {0x28, 0x84, 0xB3, 0xB4, 0x00, 0x00, 0x00, 0xB6};  // Cold line
const DeviceAddress TEMP_OUT_ADDR = {0x28, 0x4D, 0xF1, 0xBA, 0x00, 0x00, 0x00, 0xC0};   // Outlet (mixed) line

// ====================================================
// Servo Motors (MG996R)
// ====================================================

constexpr uint8_t SERVO_PIN_HOT = 19;   // Hot valve servo (GPIO 19)
constexpr uint8_t SERVO_PIN_COLD = 18;  // Cold valve servo (GPIO 18)

// --- Calibration Values ---
// Calibrated using: firmware/tools/servo_calibration/servo_calibration.ino

constexpr unsigned SERVO_HOT_MIN_US = 1180;   // µs at fully open position
constexpr unsigned SERVO_HOT_MAX_US = 2080;   // µs at fully closed position
constexpr unsigned SERVO_COLD_MIN_US = 1120;  // µs at fully open position
constexpr unsigned SERVO_COLD_MAX_US = 2080;  // µs at fully closed position
constexpr unsigned SERVO_GUARD_US = 15;       // Guard offset to avoid hard stops

// ====================================================
// Flow Sensor (YF-S201)
// ====================================================

constexpr uint8_t FLOW_PIN = 21;               // Flow sensor signal pin (GPIO 21)
constexpr float FLOW_K_PULSES_PER_ML = 7.5f;   // K-factor: pulses per mL of water (placeholder; calibrate later)
constexpr unsigned FLOW_WINDOW_MS = 500;       // Sampling window (ms)
constexpr unsigned FLOW_FILTER_TAU_MS = 1000;  // EMA time constant for flow smoothing (ms)

// ====================================================
// Emergency Stop Switch
// ====================================================

constexpr uint8_t ESTOP_PIN = 33;  // E-stop button input

// ====================================================
// PID Controller (Outlet Temperature)
// ====================================================

constexpr float PID_KP = 0.025f;     // Proportional gain
constexpr float PID_KI = 0.005f;     // Integral gain (per second)
constexpr float PID_KD = 0.0f;       // Derivative gain
constexpr float PID_OUT_MIN = 0.0f;  // Output lower bound (mix ratio)
constexpr float PID_OUT_MAX = 1.0f;  // Output upper bound (mix ratio)
constexpr float PID_ERROR_DEADBAND_F = 0.2f;      // No integrate/drive when |error| < deadband
constexpr float PID_OUTPUT_SLEW_PER_SEC = 0.8f;   // Slow slew (per second, 0-1 scale)
constexpr float PID_OUTPUT_SLEW_FAST_PER_SEC = 3.0f; // Fast slew when far from setpoint
constexpr float PID_SLEW_ERROR_THRESH_F = 3.0f;   // Error threshold to use fast slew
constexpr bool PID_LOG_CSV = true;   // Enable CSV logging (time_ms,out_f,set_f,error_f,ratio)

// ====================================================
// Safety / Communication
// ====================================================

constexpr unsigned COMM_LINK_TIMEOUT_MS = 2000;  // Link-loss timeout (ms)

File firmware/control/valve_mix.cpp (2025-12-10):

#include "valve_mix.h"

#include <ESP32Servo.h>
#include <math.h>

#include "config.h"

static Servo sHot, sCold;
static bool sAttached = false;

// Soft limits (guard band applied around mechanical min/max)
static int hotSoftMin, hotSoftMax;
static int coldSoftMin, coldSoftMax;

// Last commanded pulse widths (for logging/tests)
static int g_lastHot = (SERVO_HOT_MIN_US + SERVO_HOT_MAX_US) / 2;
static int g_lastCold = (SERVO_COLD_MIN_US + SERVO_COLD_MAX_US) / 2;

// Linear interpolation between two pulse widths
static inline int lerp_us(int a, int b, float t) {
  return (int) lroundf(a + (b - a) * t);
}

void valveMixInit() {
  const int hMin = min(SERVO_HOT_MIN_US, SERVO_HOT_MAX_US);
  const int hMax = max(SERVO_HOT_MIN_US, SERVO_HOT_MAX_US);
  const int cMin = min(SERVO_COLD_MIN_US, SERVO_COLD_MAX_US);
  const int cMax = max(SERVO_COLD_MIN_US, SERVO_COLD_MAX_US);

  hotSoftMin = hMin + SERVO_GUARD_US;
  hotSoftMax = hMax - SERVO_GUARD_US;
  coldSoftMin = cMin + SERVO_GUARD_US;
  coldSoftMax = cMax - SERVO_GUARD_US;

  sHot.setPeriodHertz(50);
  sCold.setPeriodHertz(50);
  sHot.attach(SERVO_PIN_HOT);
  sCold.attach(SERVO_PIN_COLD);
  sAttached = true;

  valveMixCloseAll();
}

void valveMixCloseAll() {
  if (!sAttached) return;

  sHot.writeMicroseconds(SERVO_HOT_MAX_US);
  sCold.writeMicroseconds(SERVO_COLD_MAX_US);

  g_lastHot = SERVO_HOT_MAX_US;
  g_lastCold = SERVO_COLD_MAX_US;
}

void applyMixRatio(float ratio) {
  if (!sAttached) return;

  const float r = constrain(ratio, 0.0f, 1.0f);

  // HOT: r=0 → MAX (closed), r=1 → MIN (open)
  int hotTarget = lerp_us(SERVO_HOT_MAX_US, SERVO_HOT_MIN_US, r);
  // COLD: r=0 → MIN (open),   r=1 → MAX (closed)
  int coldTarget = lerp_us(SERVO_COLD_MIN_US, SERVO_COLD_MAX_US, r);

  hotTarget = constrain(hotTarget, hotSoftMin, hotSoftMax);
  coldTarget = constrain(coldTarget, coldSoftMin, coldSoftMax);

  sHot.writeMicroseconds(hotTarget);
  sCold.writeMicroseconds(coldTarget);
  g_lastHot = hotTarget;
  g_lastCold = coldTarget;
}

int lastHotUs() { return g_lastHot; }
int lastColdUs() { return g_lastCold; }

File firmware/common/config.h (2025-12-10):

#pragma once

#include <stdint.h>

// ====================================================
// ESP-NOW Communication
// ====================================================

// --- Configuration ---
constexpr uint8_t COMM_CHANNEL = 6;          // Wi-Fi channel (1–13)
constexpr bool COMM_USE_ENCRYPTION = false;  // Enable encryption (true/false)

// --- MAC Addresses ---
// Scanned using: firmware/tools/m2_mac_scan/m2_mac_scan.ino
static const uint8_t COMM_CTRL_MAC[6]{0x3C, 0x8A, 0x1F, 0x80, 0xA9, 0xD4};  // Control Unit
static const uint8_t COMM_UI_MAC[6]{0x8C, 0x4F, 0x00, 0x35, 0x9B, 0xF4};    // UI Unit

// --- Encryption Keys ---
static const uint8_t COMM_PMK[16]{'s', 'h', 'o', 'w', 'e', 'r', 'c', 't', 'r', 'l', '_', 'p', 'm', 'k', '1', '6'};  // Primary Master Key
static const uint8_t COMM_LMK[16]{'s', 't', 'a', 't', 'i', 'c', '_', 'l', 'm', 'k', '_', 'u', 'i', 'c', 't', 'r'};  // Local Master Key

// --- Protocol version ---
constexpr uint8_t COMM_PROTOCOL_VERSION = 1;

// --- Flag bit masks ---
constexpr uint8_t COMM_FLAG_ACK = 1 << 0;  // Acknowledgment bit
constexpr uint8_t COMM_FLAG_RUN = 1 << 1;  // Run/Stop bit
constexpr uint8_t COMM_FLAG_ERR = 1 << 2;  // Error indication bit
constexpr uint8_t COMM_FLAG_TEMP_VALID = 1 << 3;  // Outlet temperature included/valid
constexpr uint8_t COMM_FLAG_FLOW_VALID = 1 << 4;  // Flow data included/valid
// bits 5–7 reserved

// --- Payload Structure ---
typedef struct __attribute__((packed)) {
  uint32_t ms;      // timestamp (ms)
  uint16_t seq;     // sequence number
  float setpointF;  // temperature setpoint
  float flowLpm;    // flow rate (L/min), valid if COMM_FLAG_FLOW_VALID
  uint8_t flags;    // status bits (COMM_FLAG_*)
} COMM_Payload;

// ====================================================
// Setpoint configurations
// ====================================================

constexpr float SETPOINT_DEFAULT_F = 100.0f;  // Default setpoint
constexpr float SETPOINT_MIN_F = 80.0f;       // Safety lower limit
constexpr float SETPOINT_MAX_F = 120.0f;      // Safety upper limit
constexpr float SETPOINT_STEP_F = 1.0f;       // Increment/decrement step

constexpr float SETPOINT_PRESET_A_F = 98.0f;   // Preset A
constexpr float SETPOINT_PRESET_B_F = 105.0f;  // Preset B

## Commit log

2025-10-22 M1: Blink Test (Issue #1)
    [m1_blink_test.ino]
2025-10-22 M1: Read temp sensors & map addresses (Issue #2)
    [config.h, m1_temp_read_test.ino, m1_temp_scan.ino]
2025-10-22 M1: UI OLED SPI test (Issue #4)
    [config.h, m1_oled_spi_test.ino]
2025-10-22 M1: OLED "UI Ready" with Temp Icon (Issue #5)
    [config.h, m1_oled_spi_test.ino, m1_ui_ready_test.ino]
2025-10-22 Five Push Buttons (▲, ▼, ●, A, B) echo to Serial (Issue #6)
    [config.h, m1_push_button_test.ino]
2025-10-22 M1: Servo Mount Integration (Issue #3)
    [servo_mount.f3d, servo_mount.step, servo_mount.stl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]
2025-10-22 Servo sweep & capture µs limits (Issue #7)
    [config.h, m1_servo_calibration.ino, m1_servo_sweep_test.ino]
2025-10-29 M1: Replace hardcoded servo pins
    [config.h, m1_servo_sweep_test.ino, m1_temp_read_test.ino]
2025-12-10 M2: ESP-NOW static link (Issue #8)
    [config.h, m2_comm_test_ctrl.ino, m2_comm_test_ui.ino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]
2025-12-10 M2: Outlet temperature read loop + exponential filtering (Issue #9)
    [m2_outlet_temp_test_data.csv]
2025-12-10 M2: Flow sensor pulses → L/min (Issue #10)
    [m2_flow_sensor_test_data.csv]
2025-12-10 M2: Two-valve command model (Issue #11)
    [config.h, m1_servo_calibration.ino, m1_servo_sweep_test.ino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]
2025-12-10 M2: Small cleanup and consistency fixes
    [config.h, m1_blink_test.ino, m1_oled_spi_test.ino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]
2025-12-10 M2: UI sender — Setpoint entry + status line (Issue #14)
    [config.h, control.ino]
2025-12-10 M2: Small consistency fix
    [config.h, control.ino, m2_valve_mix_test.ino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]
2025-12-10 M2: Implement custom debounced button FSM (click/dbl/long/repeat)
2025-12-10 M2: PI control loop (Issue #12)
    [m2_closed_loop_v1_data.csv]
2025-12-10 M2: Safety gate: link-loss & sensor-fault → all valves closed (Issue #13)
    [config.h, control.ino, ui.ino]
2025-12-10 M2: Basic logging helper + live plot (Issue #16)
    [m2_logger_sample.csv]
2025-12-10 Replace DS18B20 sensor due to failure
    [config.h, m2_logger_live_plot.py, m2_logger_plot.py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]
2025-12-10 Display control temperature; always send hearbeat
2025-12-10 Show flow data on UI
2025-12-10 Tuning PID
2025-12-14 Add initial mixing and safety bounds for hot/cold sensors
2025-12-14 Tune PID stability and logging
    [config.h, control.ino]
2025-12-15 Batch-plot setpoint runs and refresh reports
    [setpoint_auto_100.csv, setpoint_auto_105.csv, setpoint_auto_110.csv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]
